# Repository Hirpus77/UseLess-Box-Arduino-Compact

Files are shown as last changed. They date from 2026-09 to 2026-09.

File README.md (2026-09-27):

# Useless Box Arduino Compact (v1.5)

Useless box compatta con Arduino Nano e un solo servo: levetta su **D9**, servo su **D10**, 29 comportamenti più Party Mode.

Per iniziare leggi [`INIZIA_QUI.md`](INIZIA_QUI.md) e la guida PDF in [`01_GUIDA/`](01_GUIDA/).

## Contenuto

| Cartella | Contenuto |
|---|---|
| `01_GUIDA/` | Guida PDF v1.5, istruzioni di cablaggio e posizionamento, verifiche STL |
| `02_ARDUINO/` | Sketch: prova levetta, calibrazione braccio, programma a 29 comportamenti, programma base opzionale |
| `03_STL_STAMPA/` | I nove pezzi da stampare in 3D |
| `04_STEP_MODIFICABILI/` | Gli stessi pezzi in formato STEP, modificabili |
| `05_IMMAGINI/` | Schemi di cablaggio, quote e montaggio |

`SHA256SUMS.txt` permette di verificare l'integrità dei file: `sha256sum -c SHA256SUMS.txt`.

## Ordine di lavoro

1. Stampa i nove file di `03_STL_STAMPA`.
2. Carica `prova_levetta.ino` per verificare la levetta su D9.
3. Carica `calibra_braccio.ino` e annota i quattro angoli.
4. Inserisci gli angoli in `useless_box_29_comportamenti.ino` e caricalo.

Con il computer collegato via USB il ponticello RUN va tolto; il servo si muove solo con l'alimentazione esterna a 5 V accesa.

## Licenza

Il progetto usa licenze diverse per tipo di contenuto:

| Contenuto | Licenza | File |
|---|---|---|
| Codice (`02_ARDUINO/`) | MIT | [`LICENSE`](LICENSE) |
| Hardware (`03_STL_STAMPA/`, `04_STEP_MODIFICABILI/`) | CERN-OHL-P v2 | [`LICENSE-hardware`](LICENSE-hardware) |
| Documentazione e immagini (`01_GUIDA/`, `05_IMMAGINI/`, file di testo) | CC BY-SA 4.0 | [`LICENSE-docs`](LICENSE-docs) |

© 2026 Hirpus77

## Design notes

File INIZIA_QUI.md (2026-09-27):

# Useless box compatta v1.5 - INIZIA QUI

Questa cartella contiene una sola copia di ogni file corrente.

## Ordine consigliato

1. Leggi `01_GUIDA/Guida_useless_box_compatta_v1.5_D9_D10.pdf`.
2. Stampa soltanto i nove file presenti in `03_STL_STAMPA`.
3. Esegui prima `02_ARDUINO/prova_levetta/prova_levetta.ino`.
4. Esegui `02_ARDUINO/calibra_braccio/calibra_braccio.ino` e annota i quattro angoli.
5. Inserisci gli angoli in `02_ARDUINO/useless_box_29_comportamenti/useless_box_29_comportamenti.ino`.
6. Metti `ABILITATO = true`, prova i comportamenti 1, 8 e 26, poi rimetti `COMPORTAMENTO_TEST = 0`.

## Pin definitivi

- D10 / verde: segnale servo.
- D9 / giallo: levetta.
- blu GND: centrale COM della levetta.
- rosso 5V: giunto RUN e distributore +5 V.
- nero GND: distributore GND.
- D2: libero.

Con il Mac collegato RUN deve essere tolto. Il servo si muove soltanto con il 5 V esterno collegato e acceso.

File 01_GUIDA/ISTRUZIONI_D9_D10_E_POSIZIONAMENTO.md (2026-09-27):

# Cablaggio definitivo con distributori da 5 poli e giunto da 2 poli

Questa revisione usa i componenti già acquistati:

- due distributori a leva da 5 poli;
- due giunti a leva da 2 poli;
- i cinque fili già saldati alla basetta A;
- la slitta C10 e la basetta 50 × 34 mm già previste dal progetto.

D2 resta libero. Non servono una seconda piastra, nuovi fori o modifiche alla scatola.

## 1. Mappa dei cinque fili

| Colore | Pin Nano | Destinazione |
|---|---|---|
| Verde | D10 | Giunto da 2 poli, poi segnale `S` del servo |
| Giallo | D9 | Piedino laterale `ON` della levetta |
| Blu | GND | Piedino centrale `COM` della levetta |
| Rosso | 5V | RUN, poi distributore `+5 V` da 5 poli |
| Nero | GND | Distributore GND da 5 poli |

Tutti i programmi leggono la levetta da D9 con `INPUT_PULLUP`.

## 2. Levetta

- centrale `COM`: blu GND;
- laterale che chiude il contatto nella posizione ON: giallo D9;
- altro laterale: libero e isolato.

Se ON e OFF risultano invertiti, spostare soltanto il giallo sull'altro piedino laterale.

## 3. Servo

Al servo arrivano esattamente tre collegamenti:

1. verde D10 attraverso il giunto da 2 poli al segnale `S`;
2. rosso dal distributore +5 V al rosso centrale del servo;
3. nero dal distributore GND al nero o marrone del servo.

## 4. Distributore +5 V da 5 poli

Montarlo sulla faccia della basetta rivolta verso il centro della scatola. Usare quattro sedi:

1. positivo dell'alimentatore esterno;
2. positivo del servo;
3. positivo del condensatore;
4. uscita di RUN.

La quinta sede resta libera. L'altro lato di RUN va al filo rosso 5V del Nano.

## 5. Distributore GND da 5 poli

Montarlo sulla faccia opposta della stessa basetta, rivolta verso la parete destra. Usare quattro sedi:

1. negativo dell'alimentatore esterno;
2. GND nero o marrone del servo;
3. negativo del condensatore, identificato dalla fascia;
4. filo nero GND del Nano.

La quinta sede resta libera. Il blu non entra nel distributore: va direttamente al COM della levetta.

## 6. Giunti da 2 poli

- giunto D10, prima sede: verde proveniente da D10;
- giunto D10, seconda sede: filo del contatto `S` del servo;
- giunto RUN, prima sede: rosso proveniente dal 5V del Nano;
- giunto RUN, seconda sede: ingresso del distributore +5 V.

I due giunti restano su cavetti corti fissati con una fascetta al bordo superiore della C10. Nel giunto D10 non collegare 5 V o GND.

## 7. Preparazione della basetta C10

Questa operazione si esegue fuori dalla scatola.

1. Verificare che ciascun distributore non superi 30 × 19 × 10 mm.
2. Posizionare i due distributori schiena contro schiena, nella zona centrale della basetta.
3. Mettere il +5 V sulla faccia che guarderà il centro della scatola.
4. Mettere il GND sulla faccia che guarderà la parete destra.
5. Fissarli insieme alla basetta con una fascetta sottile. Non affidarsi soltanto al biadesivo.
6. Fissare il condensatore orizzontale nella fascia superiore della faccia centrale.
7. Lasciare RUN e giunto D10 su cavetti corti, legati al bordo superiore e raggiungibili dopo aver tolto il coperchio.
8. Cablare completamente il distributore GND sul lato parete: dopo il montaggio non sarà comodo aprire le leve.
9. Inserire la basetta nelle guide C10 con i componenti orientati come indicato nello schema.
10. Usare le fascette previste dalla C10 senza stringere fino a deformare la basetta.
11. Fissare la C10 nei due fori esistenti con le due M3 × 8 previste.

Le quote esatte sono nelle tavole `04_piastra_C10_quote_mm.png` e
`05_ingombri_C10_scatola_quote_mm.png`.

## 8. Posizioni nella scatola

- C09: basetta A e Nano;
- C10: basetta 50 × 34 mm con i due distributori sulle facce opposte;
- C05: servo;
- C06: ingresso del cavo 5 V bloccato con due fascette;
- coperchio: levetta.

Non stampare alcuna C11: è stata eliminata dopo la verifica di collisione.

## 9. Percorso dei cavi

1. Dalla C06 portare rosso e nero lungo la parete destra fino alla C10.
2. Portare verde, rosso e nero dalla C10 verso il servo restando aderenti al fondo.
3. Portare rosso e nero del Nano dalla C09 ai due distributori.
4. Portare giallo D9 e blu GND direttamente alla levetta.
5. Lasciare un arco di servizio per sollevare il coperchio.
6. Nessun filo deve attraversare la zona di movimento del braccio.

## 10. Controlli senza alimentazione

1. +5 V e GND non devono essere in continuità.
2. Nero Nano, negativo alimentatore e GND servo devono essere in continuità.
3. Verde D10 e segnale `S` del servo devono essere in continuità attraverso il giunto da 2 poli.
4. Blu GND e COM della levetta devono essere in continuità.
5. Levetta ON: giallo D9 e blu GND devono essere in continuità.
6. Levetta OFF: giallo D9 e blu GND devono essere separati.
7. D2 deve risultare scollegato.
8. RUN tolto: il 5V del Nano deve essere separato dal +5 V esterno.
9. RUN inserito: il 5V del Nano deve essere collegato al +5 V esterno.

## 11. Prova con il Mac

1. Spegnere il 5 V esterno.
2. Togliere RUN.
3. Collegare il Nano al Mac.
4. Caricare `prova_levetta.ino` e aprire il monitor seriale a 115200 baud.
5. Verificare ON e OFF.
6. Caricare `calibra_braccio.ino`.
7. Collegare il servo a impianto spento.
8. Accendere il 5 V esterno per muovere il servo.

Durante la calibrazione: Mac collegato, RUN tolto, alimentatore esterno acceso.

## 12. Uso autonomo

1. Spegnere il 5 V esterno.
2. Scollegare la USB-C dal Mac.
3. Inserire RUN.
4. Accendere il 5 V esterno.

## 13. Pin usati dal codice

```cpp
const byte PIN_ARM = 10;
const byte PIN_LEVETTA = 9;
```

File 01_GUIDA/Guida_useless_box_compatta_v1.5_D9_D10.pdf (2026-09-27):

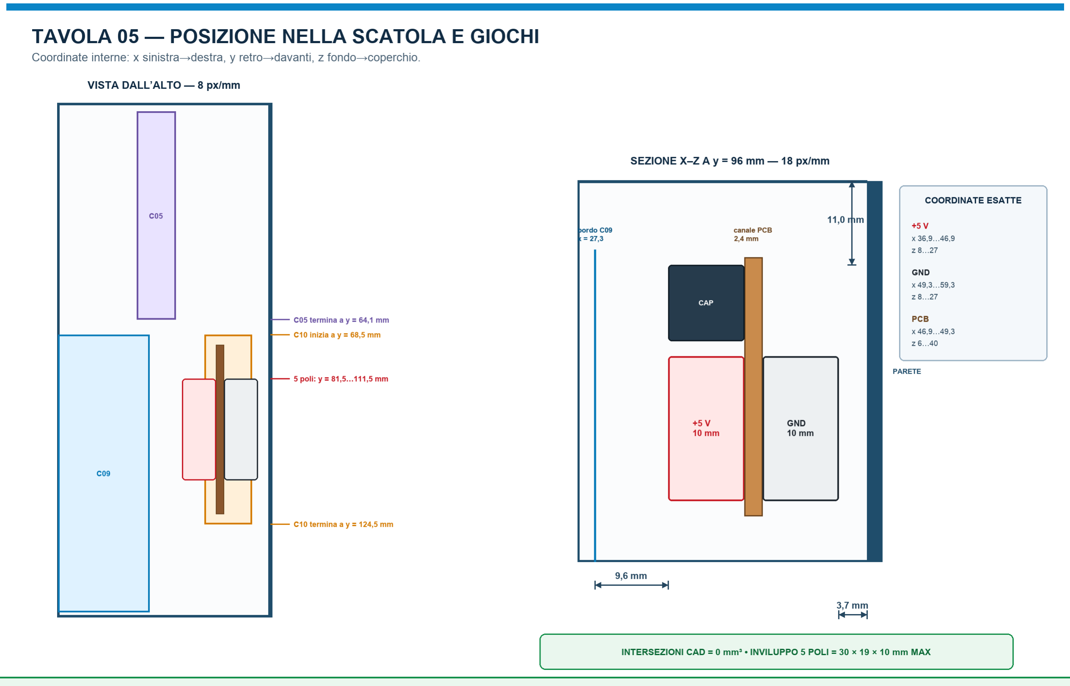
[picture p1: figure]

Useless box compatta v1.5 - D9 levetta / D10 servo | pag. 1

# Useless box compatta - versione completa 1.5

Cablaggio definitivo D9/D10, parti meccaniche corrette e calibrazione dei 29 comportamenti

Configurazione definitiva: un servo MG996R/MG995 comandato da D10; levetta letta da D9; D2 libero; alimentatore esterno 5 V / 3 A; due distributori da 5 poli e due giunti da 2 poli.

Elemento | Versione inclusa
C01 e C02 | corpo largo 68 mm; foro USB-C 15,30 x 5,30 mm; riferimenti coperchio corretti
C04 | braccio con sede squadretta D8,9
C05 | staffa servo rinforzata
C06 | fermacavo 5 V con due fascette
C10 | slitta basetta B rinforzata V2, basetta 50 x 34 mm
Arduino | D9 levetta, D10 servo, quattro sketch completi

## 1. File da stampare

File | Quantita | Indicazione di stampa
C01 corpo | 1 | fondo sul piatto; PLA; 0,20 mm; 4 pareti; 20%; senza supporti
C02 coperchio | 1 | faccia esterna sul piatto; 4 pareti; 20%; senza supporti
C03 sportello | 1 | faccia superiore sul piatto
C04 braccio D8,9 | 1 | lato della squadretta sul piatto; 5 pareti; 50%
C05 staffa servo | 1 | sul fianco come nello STL; 5 pareti; 40-50%
C06 fermacavo | 1 | piatta; due fascette
C08 piedino | 4 | piatto; incollare alla fine
C09 slitta A | 1 | base piatta; 4 pareti; 25%
C10 slitta B | 1 | base piatta; 5 pareti; 35-45%

Non stampare C11. La seconda piastra e stata eliminata: collideva con C10. I due distributori da 5 poli stanno sulle facce opposte della stessa basetta montata in C10.

Quote principali: C01 e C02 misurano 68 x 157 mm. Il vano interno e 63 x 152 x 50 mm. Il foro USB-C utile e 15,30 x 5,30 mm con tolleranza minima.

## 2. Viti e minuteria

Uso | Quantita e misura
MG996R/MG995 nella C05 | 4 x M3x12, 4 rondelle M3, 4 dadi M3; usare M3x16 se restano i gommini
C05, C09 e C10 sul fondo | 6 x M3x6 complessive, inserite dal basso
Coperchio | 2 x M3x10
Perno sportello | 1 x M3x25
C04 sulla squadretta | 2 viti piccole del servo
Squadretta sull albero | 1 vite centrale del servo
C09 e C10 | 4 fascette larghe massimo 2,5 mm
C06 | 2 fascette per bloccare il cavo 5 V

Totale viti metriche: 13. A queste si aggiungono le 3 viti fornite con il servo per squadretta e braccio.

Non avvitare le quattro M3 del servo direttamente nel PLA. Le viti attraversano asola C05 e aletta del servo; rondella e dado chiudono sul lato opposto.

## 3. Montaggio del servo e del braccio

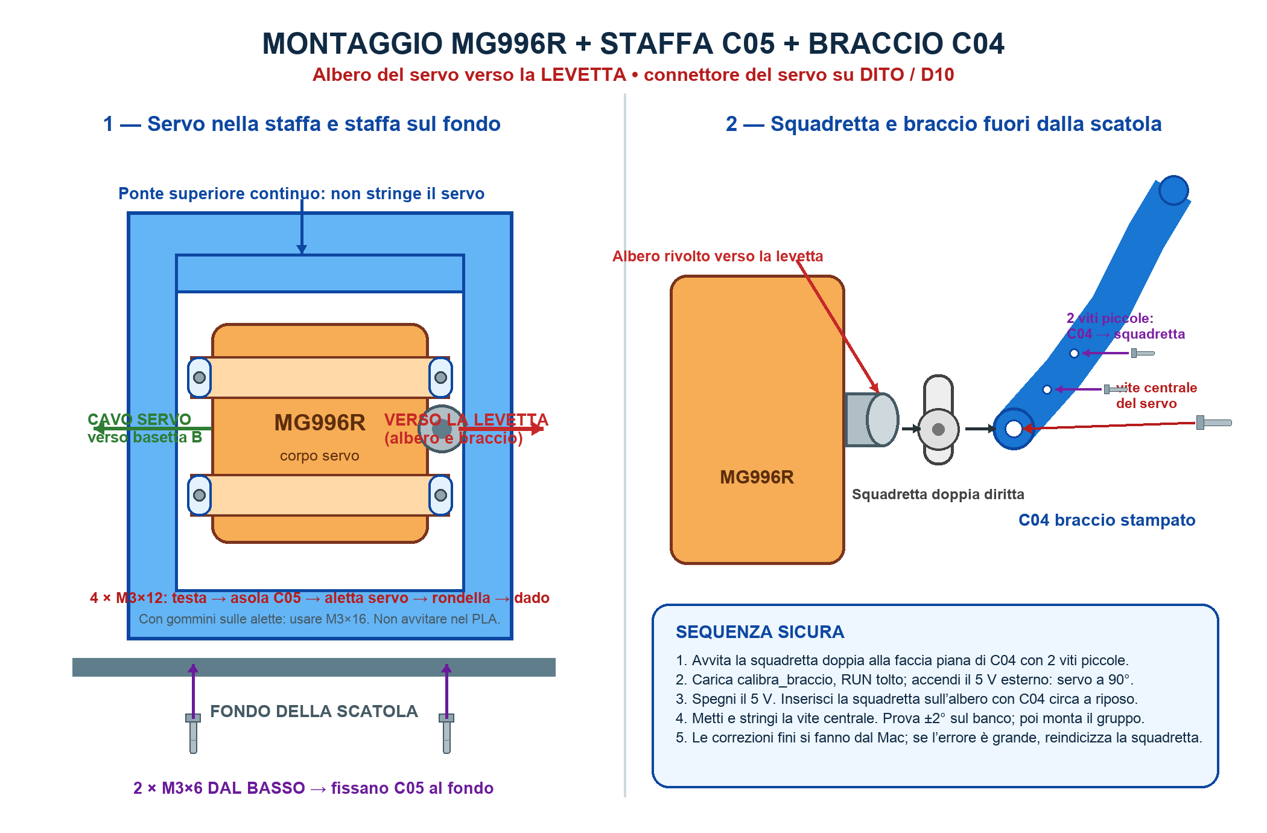
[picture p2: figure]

Orientamento: albero e braccio dal lato della levetta. Il cavo del servo esce dal lato opposto, verso l elettronica.

Sequenza: fissa C05 al fondo con due M3x6; inserisci il servo lateralmente; monta quattro M3 con rondelle e dadi; centra il servo nelle asole; serra a croce.

La squadretta doppia entra nella sede D8,9 di C04. Fissala con due viti piccole. Centra elettricamente il servo a 90 gradi, spegni il 5 V esterno, inserisci la squadretta sull albero e stringi la vite centrale.

## 4. I cinque fili della basetta A

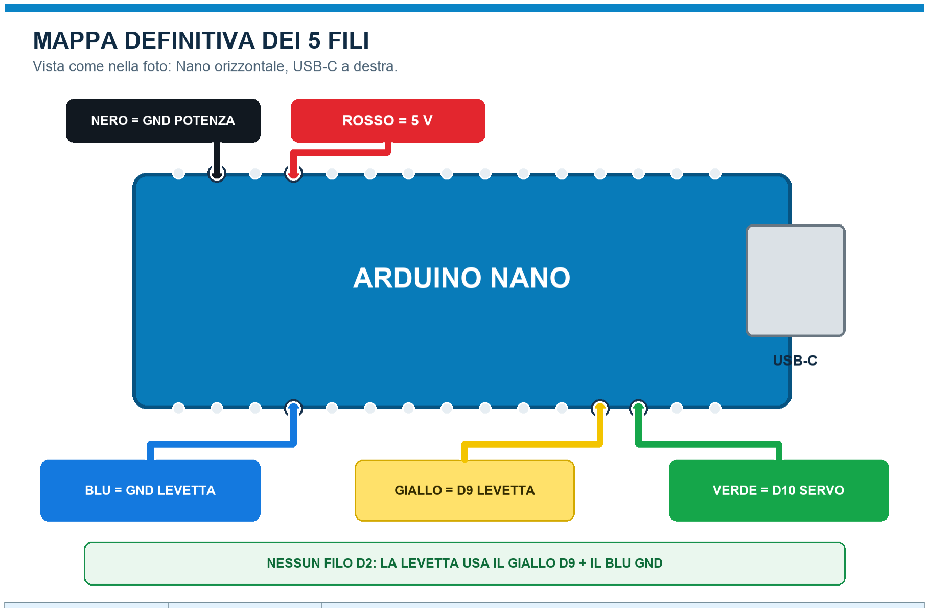
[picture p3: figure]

Colore | Pin Nano | Destinazione
Verde | D10 | giunto da 2 poli, poi segnale S del servo
Giallo | D9 | terminale laterale ON della levetta
Blu | GND | terminale centrale COM della levetta
Rosso | 5V | giunto RUN, poi distributore +5 V
Nero | GND | distributore GND

D2 resta scollegato. Non aggiungere un sesto filo.

## 5. Schema elettrico definitivo

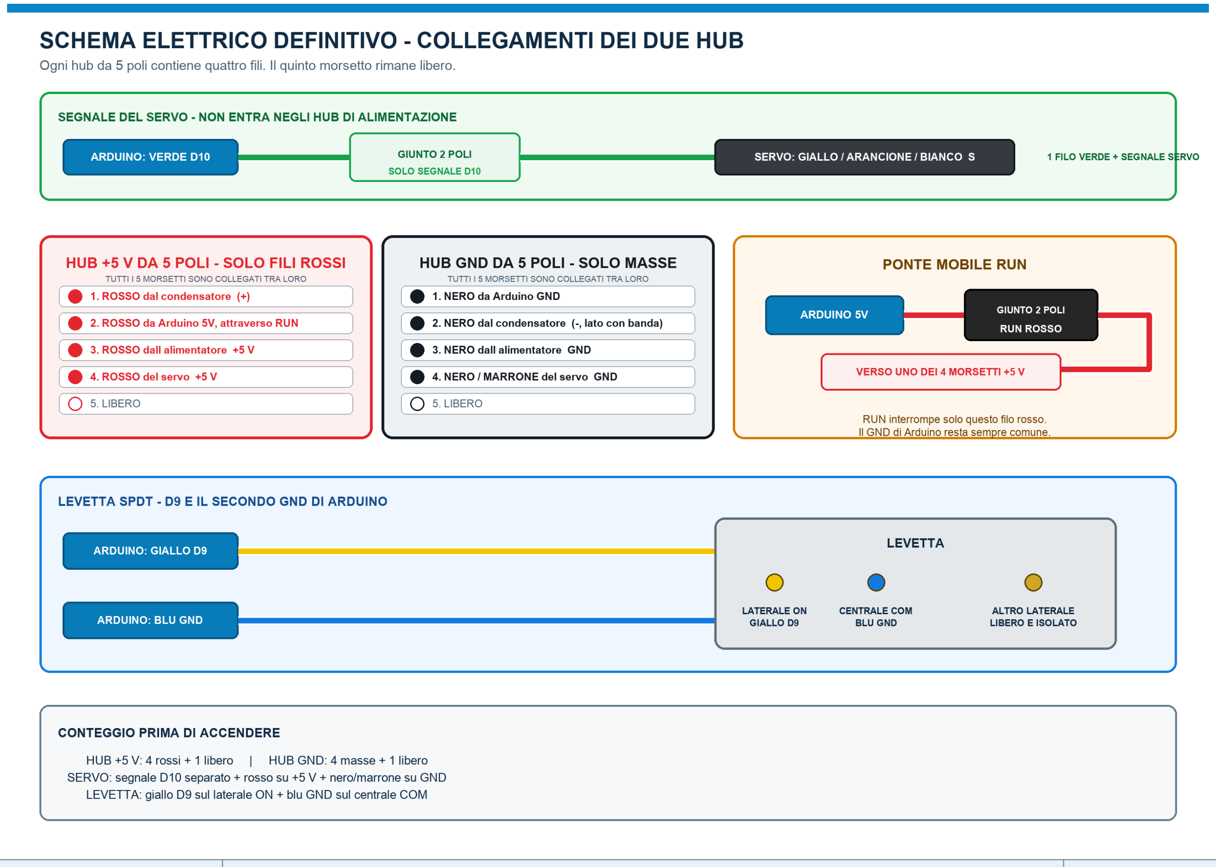
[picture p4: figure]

Hub | Quattro morsetti occupati | Quinto morsetto
+5 V, solo rossi | condensatore +; Arduino 5V attraverso RUN; alimentatore +5V; servo +5V | libero
GND, solo masse | Arduino GND nero; condensatore -; alimentatore GND; servo nero/marrone | libero
Fuori dagli hub: verde D10 passa nel giunto a 2 poli e va al segnale S del servo. Giallo D9 va al laterale ON della levetta; blu GND va al centrale COM.

RUN: interrompe soltanto il filo rosso tra 5V Arduino e hub +5 V. Il GND nero di Arduino rimane sempre collegato all hub GND.

## 6. Posizione dei componenti

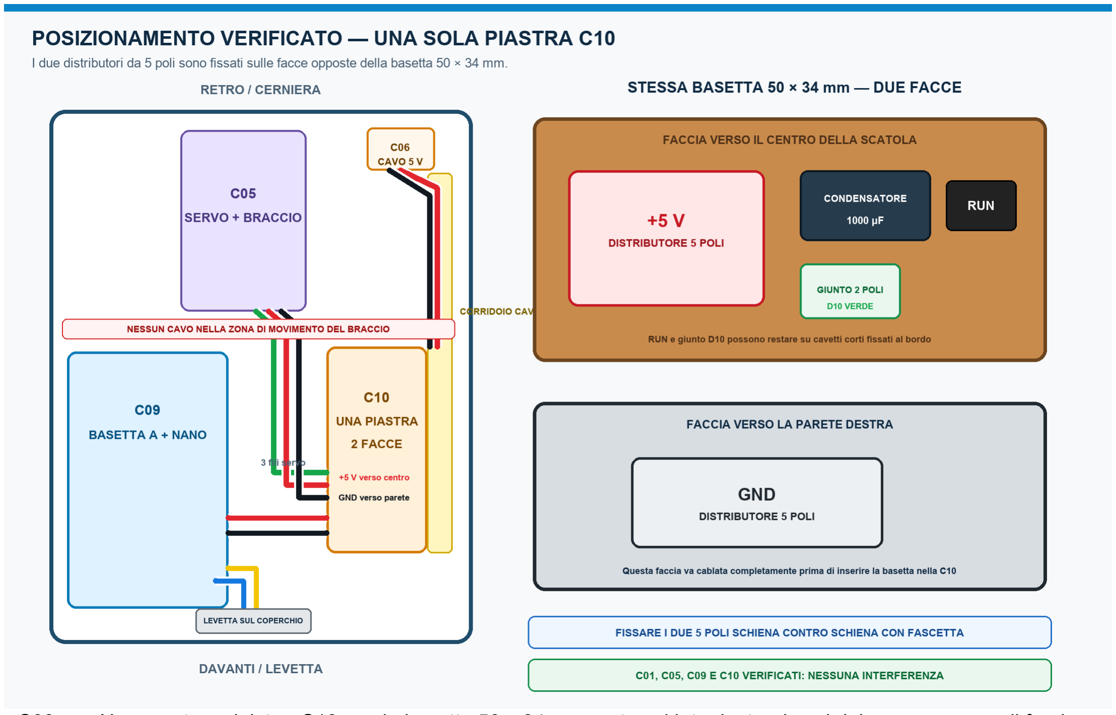
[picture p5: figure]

C09 con Nano resta a sinistra. C10 con la basetta 50 x 34 mm resta sul lato destro. I cavi del servo seguono il fondo e non entrano nella zona di movimento del braccio.

Il distributore +5 V guarda il centro della scatola. Il distributore GND guarda la parete destra e deve essere cablato completamente prima di inserire la basetta nelle guide C10.

## 7. Basetta C10: quote di montaggio

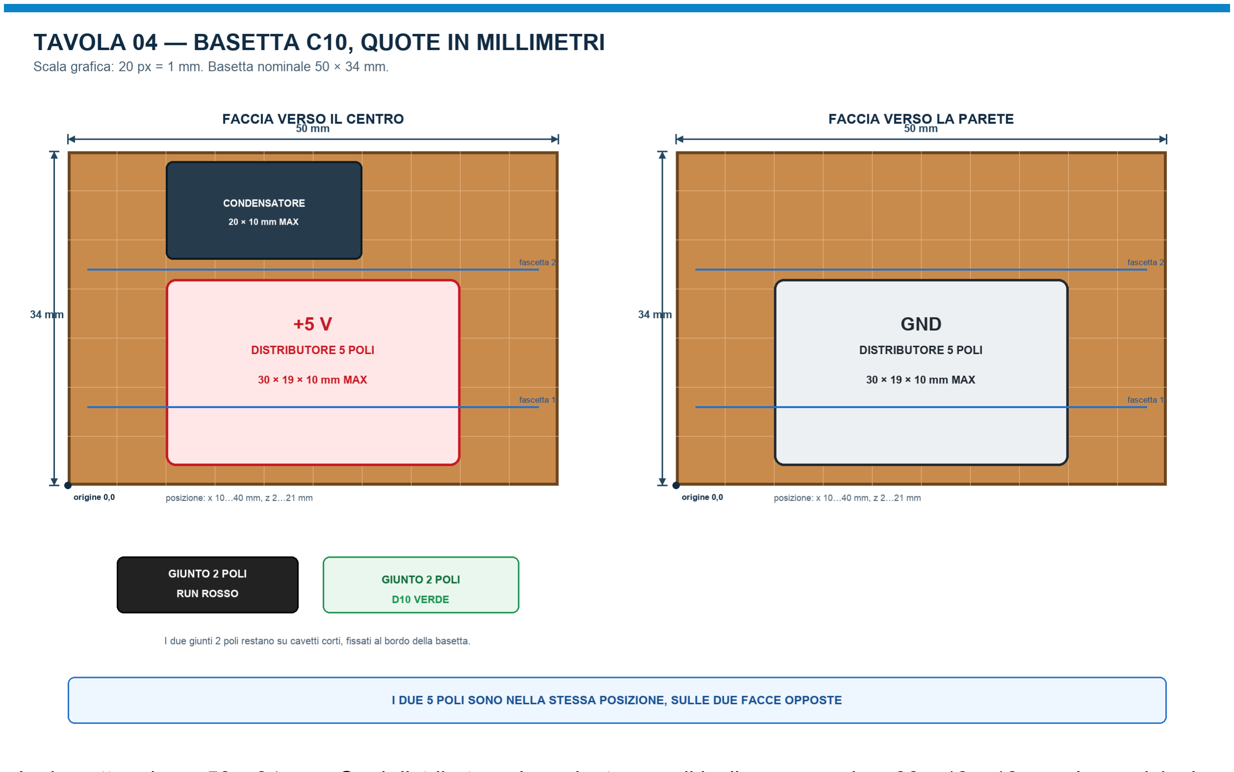
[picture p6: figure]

La basetta misura 50 x 34 mm. Ogni distributore deve rientrare nell inviluppo massimo 30 x 19 x 10 mm. Le posizioni indicate sono x 10-40 mm e z 2-21 mm sulle due facce opposte.

Fissa i due distributori schiena contro schiena con la basetta in mezzo. Usa le due fascette indicate. I due giunti da 2 poli RUN e D10 restano su cavetti corti fissati al bordo.

## 8. Ingombri verificati nella scatola

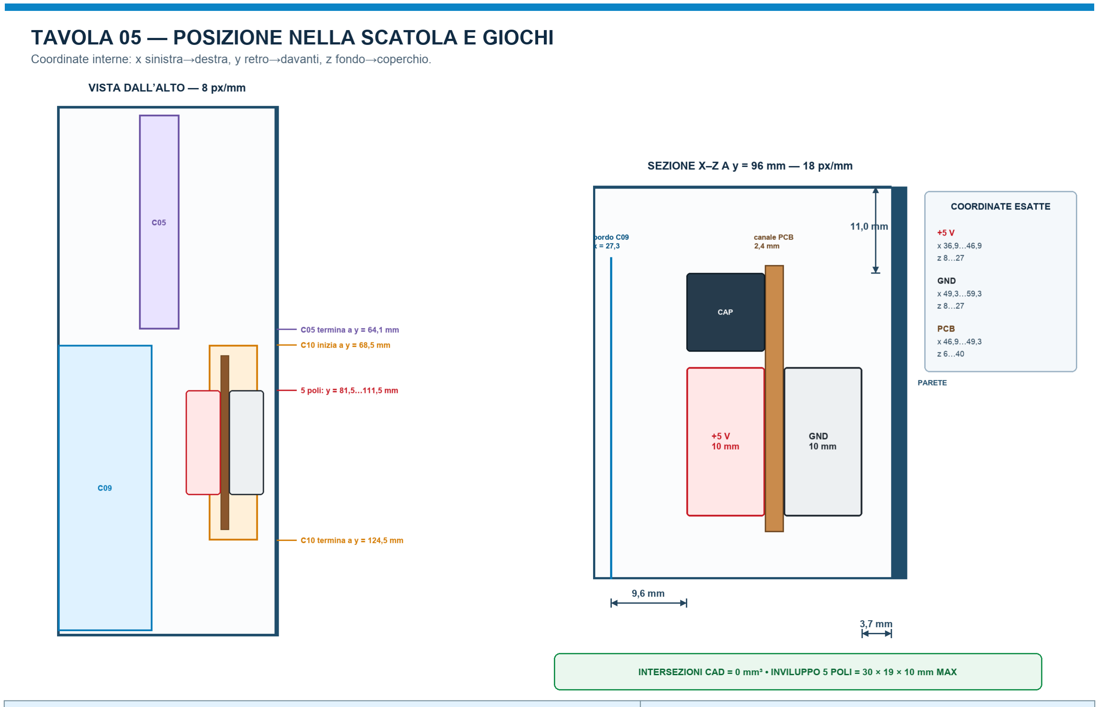
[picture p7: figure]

Controllo | Gioco verificato
Distributore GND - parete destra | 3,7 mm
Distributore +5 V - bordo C09 | 9,6 mm
Condensatore - coperchio | 11,0 mm
Intersezioni nel controllo CAD | 0 mm3

Il controllo e valido soltanto se ciascun distributore non supera 30 x 19 x 10 mm.

## 9. Ordine completo di montaggio

Passo | Operazione
1 | Stampa e prova a secco C09, C10 e C05 con le parti reali.
2 | Prepara C09 con basetta A e Nano fuori dalla scatola; applica due fascette.
3 | Prepara la basetta 50 x 34 mm con i due distributori sulle facce opposte e il condensatore.
4 | Cabla completamente il lato GND; inserisci la basetta nelle guide C10; applica due fascette.
5 | Monta il cavo 5 V nella C06 e bloccalo con due fascette antistrappo.
6 | Fissa C09, C10 e C05 dal basso con sei M3x6.
7 | Collega alimentazione, RUN, D10, servo e levetta secondo lo schema.
8 | Monta sportello, coperchio e levetta. Lascia un arco di cavo per sollevare il coperchio.
9 | Centra e monta il braccio; esegui la calibrazione dal Mac.
10 | Incolla i quattro piedini C08 solo alla fine.

Nessun cavo deve attraversare la corsa del braccio o toccare la squadretta del servo.

## 10. Controlli elettrici senza alimentazione

Misura | Risultato richiesto
+5 V verso GND | nessuna continuita
Nero Nano - negativo alimentatore - GND servo | continuita
Verde D10 - segnale S servo | continuita attraverso il giunto D10
Blu - COM levetta | continuita
Levetta ON: giallo - blu | continuita
Levetta OFF: giallo - blu | separati
RUN tolto: 5V Nano - +5 V esterno | separati
RUN inserito: 5V Nano - +5 V esterno | continuita
D2 | scollegato

Banco con Mac: spegni il 5 V esterno, togli RUN, collega la USB, poi accendi il 5 V esterno solo quando il servo deve muoversi.

Uso autonomo: spegni il 5 V, scollega la USB, inserisci RUN, poi riaccendi il 5 V.

## 11. Arduino IDE sul Mac

1. Collega il Nano con un cavo USB-C dati. RUN deve essere tolto.
2. In Arduino IDE seleziona Scheda - Arduino AVR Boards - Arduino Nano e la porta seriale comparsa.
3. Se il caricamento fallisce, prova Processore - ATmega328P (Old Bootloader).
4. Apri il Monitor seriale a 115200 baud.
5. Carica prima prova_levetta.ino. Questa prova non richiede il servo.
6. Carica poi calibra_braccio.ino. Per muovere il servo serve il 5 V esterno acceso.
Situazione | USB Mac | RUN | 5 V esterno
Caricamento sketch | collegata | tolto | spento
Prova levetta | collegata | tolto | spento
Calibrazione servo | collegata | tolto | acceso
Uso autonomo | scollegata | inserito | acceso

## 12. Prova della levetta

1. Apri 02_ARDUINO/prova_levetta/prova_levetta.ino e caricalo.
2. Apri il Monitor seriale a 115200 baud.
3. Porta la leva verso lo sportello: deve comparire ON e il LED L deve accendersi.
4. Riporta la leva indietro: deve comparire OFF e il LED L deve spegnersi.

Se ON e OFF sono invertiti, spegni tutto e sposta soltanto il filo giallo D9 sull altro terminale laterale. Il blu resta sempre sul centrale COM.

Esegui dieci commutazioni consecutive. Non devono comparire cambi casuali.

## 13. Centratura e calibrazione del braccio

1. Tieni il braccio scollegato dall albero. Carica calibra_braccio.ino con RUN tolto.
2. Accendi il 5 V esterno. Il servo va a 90 gradi. Questo indica la posizione elettrica centrale; non impone che il dito sia orizzontale o verticale.
3. Spegni il 5 V, monta squadretta e braccio circa nella posizione di riposo e stringi fuori dalla scatola.
4. Monta il gruppo. Riaccendi il 5 V e usa i comandi del Monitor seriale.
Comando | Effetto
+ / - | spostamento di 2 gradi
> / < | spostamento di 1 grado
r | ritorno lento a 90 gradi
s | stacca il segnale e libera il servo
p | stampa angolo e stato levetta
l | legge lo stato della levetta

## 14. Trovare i quattro angoli

Nome | Come identificarlo
ARM_RIPOSO | braccio dentro, sportello appoggiato, nessuna pressione e nessun ronzio
ARM_SBIRCIATA | punta appena visibile e sportello sollevato poco
ARM_QUASI | ultimo angolo vicino alla levetta senza muoverla; arretra 1-2 gradi come margine
ARM_SPINTA | primo angolo che porta la levetta da ON a OFF, poi soltanto 2 gradi aggiuntivi
Premi + tre volte. Se la punta sale verso la levetta usa angoli crescenti; se scende usa la direzione opposta. I quattro valori devono risultare tutti crescenti oppure tutti decrescenti.

La corsa RIPOSO-SPINTA ammessa dal programma e compresa tra 45 e 110 gradi. Durante la ricerca resta tra 10 e 170 gradi.

## 15. Programma con 29 comportamenti

1. Apri 02_ARDUINO/useless_box_29_comportamenti/useless_box_29_comportamenti.ino.
2. Sostituisci i valori di esempio ARM_RIPOSO, ARM_SBIRCIATA, ARM_QUASI e ARM_SPINTA con quelli misurati.
3. Lascia PIN_ARM = 10 e PIN_LEVETTA = 9.
4. Imposta ABILITATO = true.
5. Per il primo collaudo usa COMPORTAMENTO_TEST = 1, poi 8 e 26. Dopo le prove rimettilo a 0.
6. Carica il programma definitivo. Con TEST = 0 tornano la scelta automatica dei 29 comportamenti e il Party Mode.

Se compare Levetta ancora ON, aumenta ARM_SPINTA di 2 gradi nella direzione utile. Se il servo urta, ronza o forza, riduci la corsa e ricontrolla QUASI e SPINTA.

## 16. Collaudo finale e diagnosi

Sintomo | Controllo
Monitor funziona ma servo fermo | 5 V esterno acceso; verde su D10/S; massa comune; almeno 4,8 V durante il comando
Servo si muove senza controllo | GND servo e GND Nano realmente comuni; segnale D10 integro; nessun falso contatto nel giunto
Nano si spegne o si riavvia | tensione sotto carico; polarita; alimentatore; condensatore vicino ai distributori
Levetta non cambia stato | giallo D9 sul laterale attivo; blu sul centrale COM; INPUT_PULLUP
Servo ronza a riposo | ridurre pressione meccanica; correggere ARM_RIPOSO; verificare che il braccio non tocchi
Braccio urta la scatola | orientamento dell albero; sede D8,9; reindicizzare la squadretta a corrente spenta
Prova finale: esegui 20 cicli. La tensione deve restare almeno 4,8 V; la Nano non deve riavviarsi; il servo non deve restare bloccato o caldo.

Verifiche file: nove STL inclusi, tutti appartenenti alla revisione corrente. C01/C02 sono la versione larga 68 mm; C04 e la revisione D8,9; C06 e C10 sono le revisioni rinforzate. Il controllo di ingombro C01/C05/C09/C10 con i due distributori ha dato 0 mm3 di intersezioni.

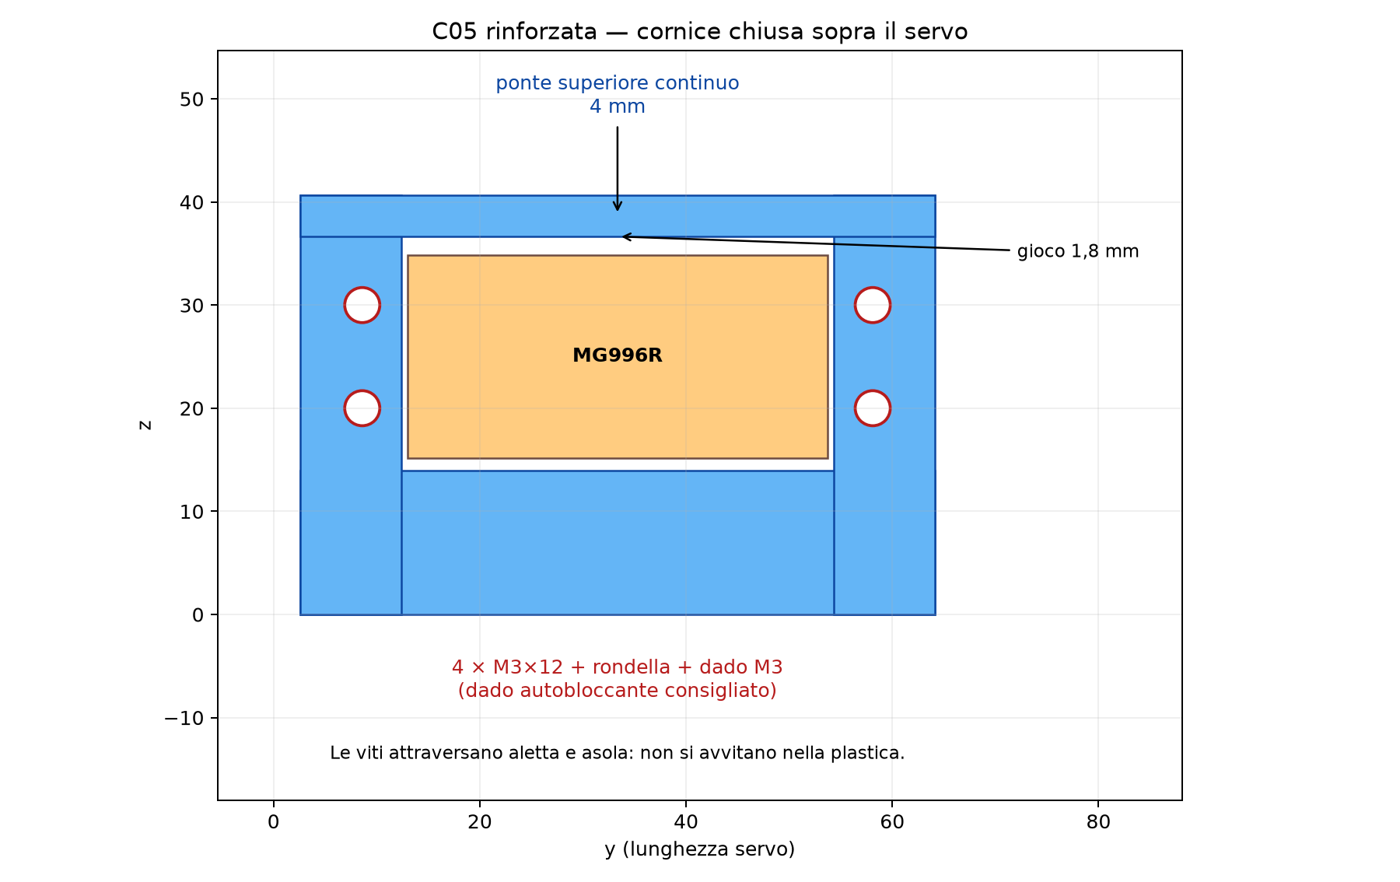
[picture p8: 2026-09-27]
05_IMMAGINI/07_staffa_C05.png

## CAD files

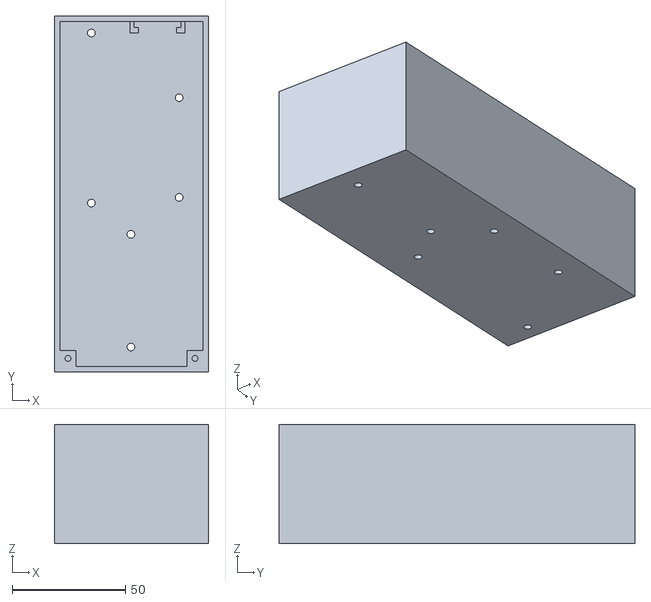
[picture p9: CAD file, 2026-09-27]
03_STL_STAMPA/C01_corpo_5mm_USB_Nano_15.30x5.30.stl
68.0 x 157.0 x 52.5

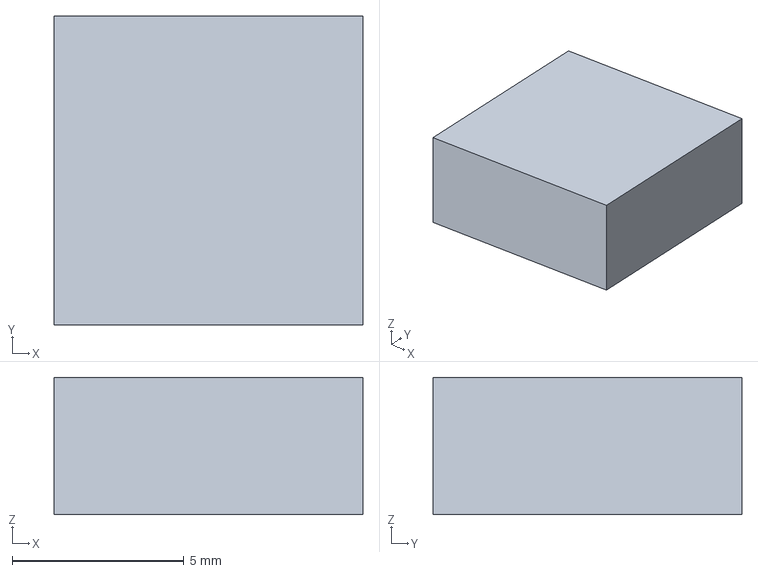
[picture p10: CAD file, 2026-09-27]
04_STEP_MODIFICABILI/C08_piedino_9x9x4.step
9.00 x 9.00 x 4.00 mm

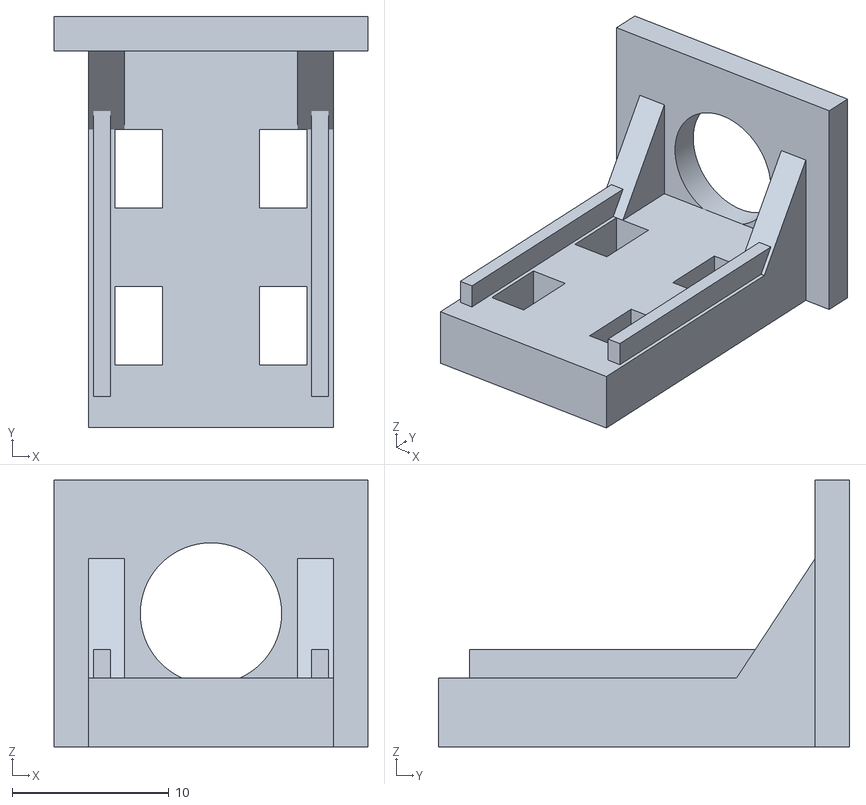
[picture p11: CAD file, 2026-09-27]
03_STL_STAMPA/C06_piastra_cavo_5V_fermacavo_2_fascette.stl
20.0 x 26.2 x 17.0

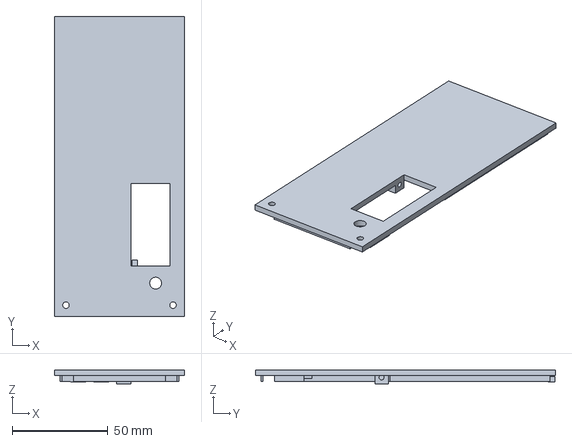
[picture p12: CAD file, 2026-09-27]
04_STEP_MODIFICABILI/C02_coperchio_5mm_interruttore_allineato.step
68.0 x 157.0 x 7.50 mm

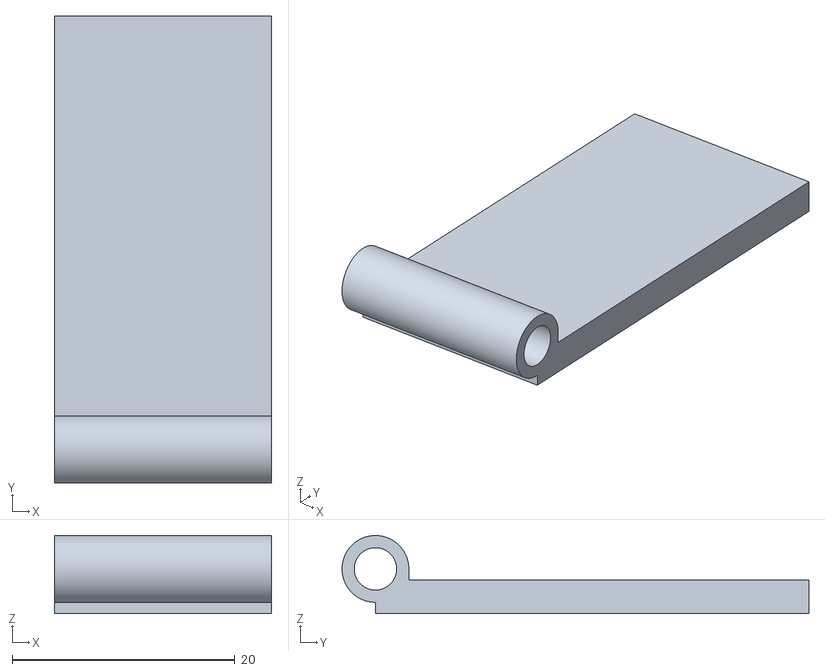
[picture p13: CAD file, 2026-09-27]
03_STL_STAMPA/C03_sportello.stl
19.5 x 41.9 x 7.00

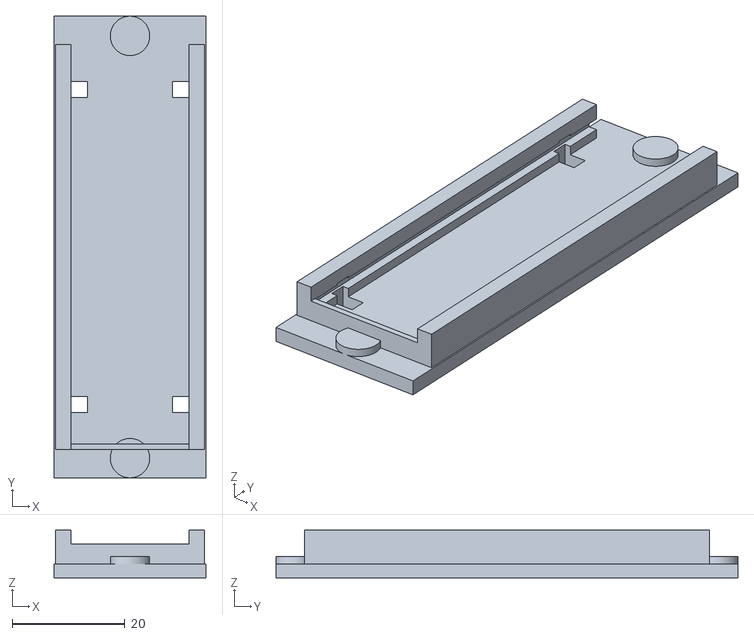
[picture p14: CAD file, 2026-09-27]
03_STL_STAMPA/C09_slitta_basetta_A_23.5x70.stl
27.0 x 82.0 x 8.50

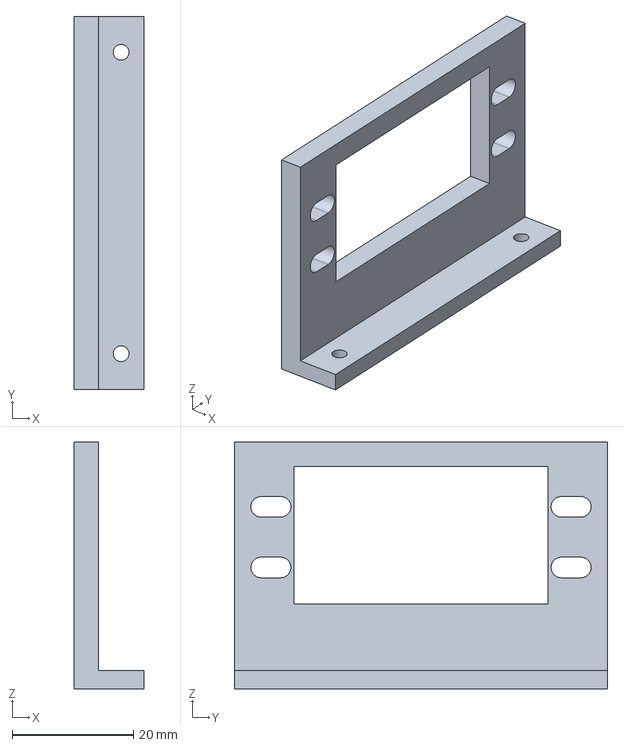
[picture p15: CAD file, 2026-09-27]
04_STEP_MODIFICABILI/C05_staffa_servo_RINFORZATA.step
11.5 x 61.5 x 40.6 mm

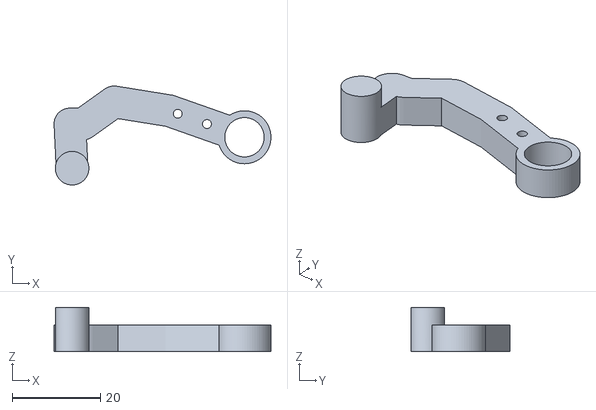
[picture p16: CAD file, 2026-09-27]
03_STL_STAMPA/C04_braccio_incastro_squadretta_D8.9.stl
49.1 x 22.4 x 10.0

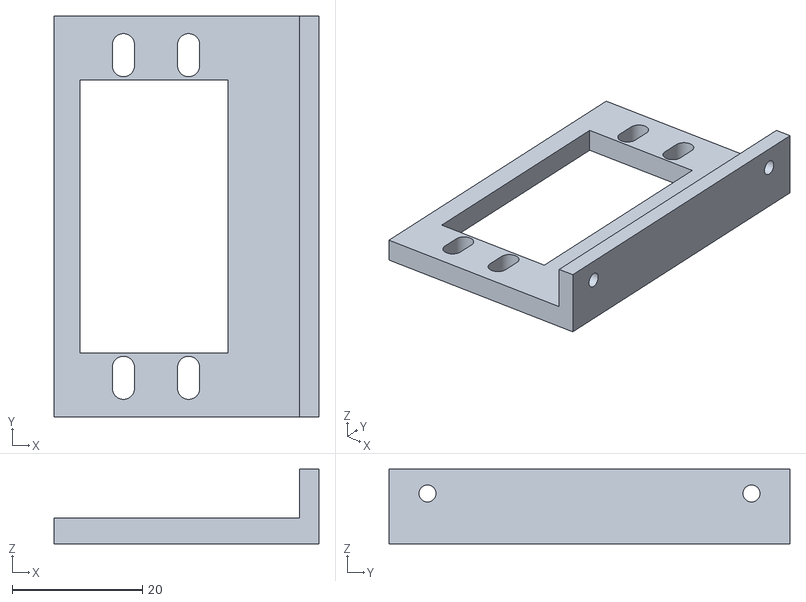
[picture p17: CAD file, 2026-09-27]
03_STL_STAMPA/C05_staffa_servo_RINFORZATA.stl
40.7 x 61.5 x 11.5

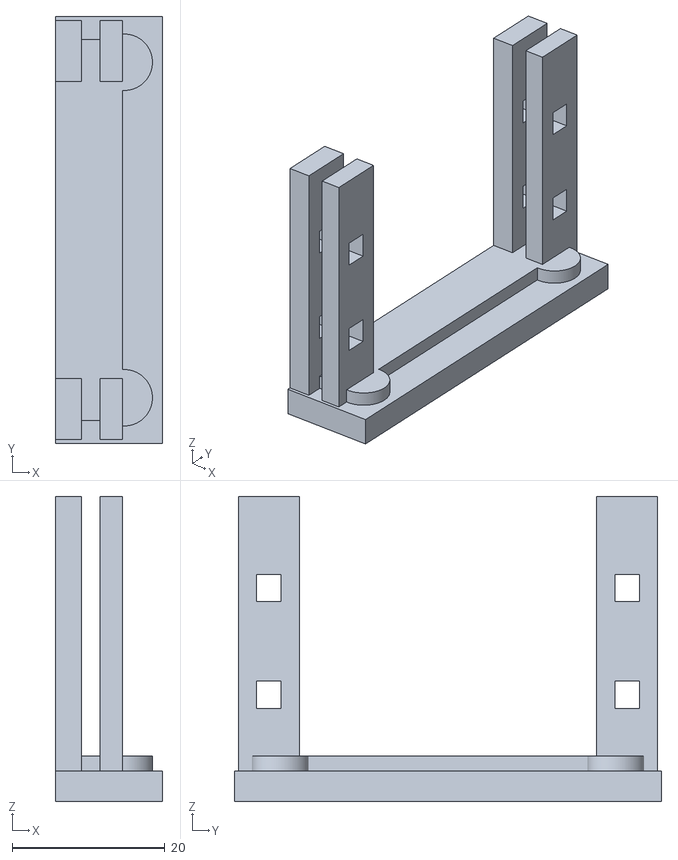
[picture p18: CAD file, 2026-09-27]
03_STL_STAMPA/C10_slitta_verticale_basetta_B_RINFORZATA_V2_50x34.stl
14.0 x 56.0 x 40.0

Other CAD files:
04_STEP_MODIFICABILI/C06_piastra_cavo_5V_fermacavo_2_fascette.step
03_STL_STAMPA/C08_piedino_9x9x4.stl
04_STEP_MODIFICABILI/C09_slitta_basetta_A_23.5x70.step
04_STEP_MODIFICABILI/C03_sportello.step
04_STEP_MODIFICABILI/C01_corpo_5mm_USB_Nano_15.30x5.30.step
04_STEP_MODIFICABILI/C10_slitta_verticale_basetta_B_RINFORZATA_V2_50x34.step
03_STL_STAMPA/C02_coperchio_5mm_interruttore_allineato.stl
04_STEP_MODIFICABILI/C04_braccio_incastro_squadretta_D8.9.step

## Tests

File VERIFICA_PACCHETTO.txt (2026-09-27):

VERIFICA PACCHETTO v1.5

PDF: 17 pagine renderizzate e controllate visivamente
STL: 9 su 9 chiusi, bordi non manifold = 0
STEP: 9 file presenti
Arduino INO: 4 file; controllo sintattico superato su tutti
Pin levetta: D9 in tutti gli sketch
Pin servo: D10 in tutti gli sketch che comandano il servo
D2: non usato
Collisioni C01/C05/C09/C10 e distributori: 0 mm3
C11: esclusa dal pacchetto
Pagina 6: schema ricontrollato; hub +5 V con 4 rossi + 1 libero; hub GND con 4 masse + 1 libero

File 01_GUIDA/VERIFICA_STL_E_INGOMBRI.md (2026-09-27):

# Verifica STL e ingombri del montaggio elettrico

## File verificati nell'assieme

- C01 corpo finale v1.7, interno 63 × 152 × 50 mm;
- C05 staffa servo;
- C09 slitta basetta A;
- C10 slitta verticale rinforzata V2;
- basetta 50 × 34 mm inserita nella C10;
- due distributori da 5 poli modellati con ingombro conservativo massimo 30 × 19 × 10 mm;
- condensatore modellato con ingombro 20 × 10 × 10 mm.

## Posizione verificata

I due distributori vengono fissati schiena contro schiena sulle due facce della stessa basetta 50 × 34 mm:

- distributore +5 V sulla faccia rivolta verso il centro della scatola;
- distributore GND sulla faccia rivolta verso la parete destra;
- ingombro lungo y: 81,5–111,5 mm;
- ingombro in altezza: z 8–27 mm;
- condensatore sulla fascia superiore della faccia centrale: z 29–39 mm.

La faccia rivolta verso la parete deve essere cablata prima di inserire la basetta nella C10.

## Risultati delle intersezioni CAD

Volume di intersezione con C01, C05, C09 e C10:

- distributore +5 V: 0 mm³;
- distributore GND: 0 mm³;
- condensatore: 0 mm³.

## Margini minimi calcolati

- distributore GND–parete destra: 3,7 mm;
- distributore +5 V–C09: 9,6 mm;
- zona distributori–C05: 17,4 mm;
- distributori–appoggio inferiore C10: 2,0 mm;
- distributori–condensatore: 2,0 mm;
- condensatore–coperchio: 11,0 mm.

## Decisione

La seconda piastra C11 è stata eliminata perché interferiva con la base e con il montante anteriore della C10. Non va stampata.

La soluzione verificata usa C01, C09 e C10 già esistenti e non richiede alcuna modifica alla scatola né nuovi STL.

La verifica vale per distributori non più grandi di 30 × 19 × 10 mm. Se i pezzi acquistati superano anche una sola di queste misure, occorre ridisegnare il supporto.

## Integrità dei file STL attivi

Controllo mesh eseguito sui file correnti:

| Pezzo | Chiuso | Normali coerenti | Corpi |
|---|---:|---:|---:|
| C01 corpo finale v1.7 | sì | sì | 1 |
| C02 coperchio finale v1.7 | sì | sì | 1 |
| C03 sportello | sì | sì | 1 |
| C04 braccio D8,9 | sì | sì | 1 |
| C05 staffa servo | sì | sì | 1 |
| C06 fermacavo | sì | sì | 1 |
| C08 piedino | sì | sì | 1 |
| C09 slitta A | sì | sì | 1 |
| C10 slitta B rinforzata V2 | sì | sì | 1 |

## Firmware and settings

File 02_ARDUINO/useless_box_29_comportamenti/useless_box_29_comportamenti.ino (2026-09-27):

/*
 * USELESS BOX COMPATTA - 29 comportamenti + Party Mode + personalita'
 * Porting dello sketch UselessBox.ino (17 gennaio 2026, Nano + SG90)
 * sulla box compatta: 1 servo MG996R, braccio curvo che apre lo sportello.
 *
 * COLLEGAMENTI (come useless_box_compatta.ino)
 *   filo verde D10 = segnale del solo servo MG996R
 *   filo giallo D9 = ingresso levetta
 *   D9 = levetta (COM a GND, ON a D9)     LED "L" su D13
 *   Banco col Mac: RUN tolto; Nano dal Mac; servo dal 5 V esterno.
 *   Autonomo: Mac scollegato; RUN inserito; 5 V esterno acceso.
 *
 * DIFFERENZE RISPETTO ALLO SKETCH DI GENNAIO
 *   - Levetta con INPUT_PULLUP: ON = LOW (a gennaio: pull-down, ON = HIGH).
 *   - Le posizioni non sono piu' 10..170 gradi ma PERCENTUALI della corsa
 *     fra ARM_RIPOSO (0 %) e ARM_SPINTA (100 %), misurati con calibra_braccio.
 *   - Tutte le finte si fermano al massimo ad ARM_QUASI (punta vicina alla
 *     levetta ma senza muoverla). Solo spingi() va oltre.
 *   - spingi() si ferma appena la levetta passa a OFF; se arriva a SPINTA e la
 *     levetta e' ancora ON aspetta al massimo 0,22 s e torna (niente stallo).
 *   - Se l'utente rimette OFF durante una finta o una pausa, il braccio rientra.
 *   - I comportamenti che a gennaio "spegnevano due volte" ora la seconda volta
 *     arrivano solo ad ARM_QUASI: la levetta e' gia' OFF, spingerla ancora
 *     manderebbe il servo in stallo contro il fine corsa.
 *   - Tempi scalati: ogni velocita' 1..8 dura quanto a gennaio sull'intera corsa
 *     (min 4 ms/grado per non lanciare lo sportello).
 *   - Codice segreto per il Party Mode: 3 "sfarfallate" (ON e subito OFF entro
 *     0,35 s) in meno di 3 s. A gennaio servivano 5 ON in 3 s, impossibili
 *     mentre il braccio lavora.
 *
 * CALIBRAZIONE: usa calibra_braccio.ino e annota QUATTRO angoli:
 *   RIPOSO    braccio dentro, sportello appoggiato, nessun ronzio
 *   SBIRCIATA punta appena fuori dallo sportello
 *   QUASI     ultimo angolo in cui la levetta NON si muove ancora
 *   SPINTA    levetta scattata su OFF + 2 gradi (non di piu')
 * Poi ABILITATO = true.
 */
#include <Servo.h>

const bool ABILITATO = true;
// 0 = scelta automatica; 1..29 = forza quel comportamento per il collaudo.
// Dopo le prove rimettere sempre 0.
const byte COMPORTAMENTO_TEST = 0;
const int ARM_RIPOSO    = 80;   // valori di ESEMPIO: sostituiscili con i tuoi
const int ARM_SBIRCIATA = 104;
const int ARM_QUASI     = 152;
const int ARM_SPINTA    = 158;

const byte PIN_ARM = 10;
const byte PIN_LEVETTA = 9;
const byte PIN_LED = 13;

const unsigned long ANTIRIMBALZO_MS = 30;
const unsigned long TENUTA_SPINTA_MS = 220;
const unsigned long STACCA_DOPO_MS = 600;
const unsigned long PERSONALITA_MS = 20000;   // memoria personalita' (gennaio: 20 s)
const unsigned long FINESTRA_SEGRETO_MS = 3000;
const unsigned long SFARFALLATA_MS = 350;
const byte SFARFALLATE_PER_PARTY = 3;
const byte DURATA_PARTY = 4;                  // attivazioni in Party Mode

Servo arm;
int armAt = ARM_RIPOSO;          // angolo attuale (gradi servo)
bool dopoSpinta = false;         // dopo lo spegnimento i movimenti non si annullano
int pSbirciata = 40, pQuasi = 80;

bool stabileOn = false, ultimoGrezzo = false, prontoPerOn = false;
unsigned long cambiatoAlle = 0, fermoDalle = 0, ultimaAttivazione = 0;
int attivazioni = 0;
bool partyMode = false;
byte partyRestanti = 0;
byte sfarfallate = 0;
unsigned long primaSfarfallata = 0;

// ------------------------------------------------------------ utilita'
bool levettaOn() { return digitalRead(PIN_LEVETTA) == LOW; }

int corsa() { return abs(ARM_SPINTA - ARM_RIPOSO); }

int percento(int angolo) {
  return (long)(angolo - ARM_RIPOSO) * 100 / (ARM_SPINTA - ARM_RIPOSO);
}

int angolo(int pct) {
  return ARM_RIPOSO + (long)(ARM_SPINTA - ARM_RIPOSO) * pct / 100;
}

bool calibrazioneValida() {
  const bool cresc = ARM_RIPOSO < ARM_SBIRCIATA && ARM_SBIRCIATA < ARM_QUASI && ARM_QUASI < ARM_SPINTA;
  const bool decr  = ARM_RIPOSO > ARM_SBIRCIATA && ARM_SBIRCIATA > ARM_QUASI && ARM_QUASI > ARM_SPINTA;
  return (cresc || decr) && corsa() >= 45 && corsa() <= 110 &&
         ARM_RIPOSO >= 5 && ARM_RIPOSO <= 175 && ARM_SPINTA >= 5 && ARM_SPINTA <= 175;
}

void collega() {
  if (!arm.attached()) { arm.write(armAt); arm.attach(PIN_ARM); }
}

// Velocita' 1..8 come a gennaio: stessa DURATA sull'intera corsa.
unsigned int msPerGrado(byte vel) {
  unsigned int durata = vel <= 2 ? 6400 : vel <= 4 ? 1600 : vel <= 6 ? 533 : 160;
  unsigned int ms = durata / corsa();
  return ms < 4 ? 4 : ms;
}

// Pausa che si interrompe se l'utente rimette OFF (prima della spinta).
bool pausa(unsigned long ms) {
  const unsigned long t0 = millis();
  while (millis() - t0 < ms) {
    if (!dopoSpinta && !levettaOn()) return true;
    delay(2);
  }
  return false;
}

// Va alla percentuale pct (limitata ad ARM_QUASI). true = annullato.
bool vai(int pct, byte vel) {
  pct = constrain(pct, 0, pQuasi);
  const int target = angolo(pct);
  const unsigned int ms = msPerGrado(vel);
  collega();
  const int dir = target > armAt ? 1 : -1;
  while (armAt != target) {
    armAt += dir;
    arm.write(armAt);
    delay(ms);
    if (!dopoSpinta && !levettaOn()) return true;
  }
  return false;
}

// Scatto immediato (come myServo.write di gennaio), limitato ad ARM_QUASI.
bool scatta(int pct, unsigned long attesa) {
  pct = constrain(pct, 0, pQuasi);
  collega();
  armAt = angolo(pct);
  arm.write(armAt);
  return pausa(attesa);
}

// Spinta vera: si ferma appena la levetta va su OFF.
void spingi(byte vel) {
  const unsigned int ms = msPerGrado(vel);
  collega();
  const int dir = ARM_SPINTA > armAt ? 1 : -1;
  while (armAt != ARM_SPINTA && levettaOn()) {
    armAt += dir;
    arm.write(armAt);
    delay(ms);
  }
  const unsigned long t0 = millis();
  while (levettaOn() && millis() - t0 < TENUTA_SPINTA_MS) delay(5);
  if (levettaOn()) {
    digitalWrite(PIN_LED, HIGH);
    Serial.println(F("Levetta ancora ON: aumenta ARM_SPINTA di 2 gradi."));
    // si stacca subito dalla levetta: niente stallo nel resto del comportamento
    const int dq = angolo(pQuasi) > armAt ? 1 : -1;
    while (armAt != angolo(pQuasi)) { armAt += dq; arm.write(armAt); delay(4); }
  } else {
    digitalWrite(PIN_LED, LOW);
  }
  dopoSpinta = true;
}

void aRiposo(byte vel) {
  const unsigned int ms = msPerGrado(vel);
  collega();
  const int dir = ARM_RIPOSO > armAt ? 1 : -1;
  while (armAt != ARM_RIPOSO) { armAt += dir; arm.write(armAt); delay(ms); }
  fermoDalle = millis();
}

void lampeggia(byte volte) {
  for (byte i = 0; i < volte; i++) {
    digitalWrite(PIN_LED, HIGH); delay(200);
    digitalWrite(PIN_LED, LOW);  delay(200);
  }
}

// Se una mossa viene annullata (utente su OFF) il comportamento finisce;
// il rientro lo fa sempre esegui().
#define V(p, v)   do { if (vai((p), (v))) return; } while (0)
#define S(p, ms)  do { if (scatta((p), (ms))) return; } while (0)
#define W(ms)     do { if (pausa(ms)) return; } while (0)
#define SPINGI(v) spingi(v)

// Punti della corsa (percentuali). A gennaio: INSIDE=10, OUTSIDE=170.
const int P_BUSSA = 18;   // alza appena lo sportello (bussa da sotto)
#define P_SBIRCIA pSbirciata
#define P_QUASI   pQuasi

// ------------------------------------------------------------ 29 comportamenti
void c01_Normale()        { V(0,5); SPINGI(5); W(300); }
void c02_Lento()          { SPINGI(2); W(300); }
void c03_Veloce()         { SPINGI(8); W(200); }
void c04_VelocitaVariabile() { V(50,3); SPINGI(7); W(300); }
void c05_FintaSingola()   { V(20,5); W(500); SPINGI(5); W(300); }
void c06_DoppiaFinta()    { V(15,5); W(400); V(30,5); W(400); SPINGI(5); W(300); }
void c07_FintaConRitorno(){ V(38,5); W(300); V(25,4); W(200); SPINGI(6); W(300); }
void c08_Cucu()           { V(P_SBIRCIA,4); W(400); V(0,6); W(1000); SPINGI(7); W(300); }
void c09_Tremante() {
  int p = 0;
  while (p < P_QUASI - 5) {
    p += 5;
    S(p, 50); S(p - 2, 50); S(p + 2, 50);
  }
  SPINGI(8); W(300);
}
void c10_PigroEstremo()   { W(random(3000, 5000)); SPINGI(8); W(200); }
void c11_DoppioSpegnimento() {
  SPINGI(6); W(300); V(0,6); W(500);
  V(P_QUASI,7); W(300);             // seconda volta: controlla soltanto
}
void c12_Indeciso()       { V(P_QUASI,5); W(800); V(0,5); W(2000); SPINGI(6); W(300); }
void c13_ToccToc() {
  for (byte i = 0; i < 3; i++) { S(P_BUSSA, 150); S(0, 150); }
  W(500); SPINGI(6); W(300);
}
void c14_Balletto() {
  for (byte i = 0; i < 4; i++) { V(22,6); V(34,6); }
  SPINGI(6); W(300);
}
void c15_Beffa()          { V(P_QUASI,8); W(800); SPINGI(2); W(300); }
void c16_SbattiSportello() {
  SPINGI(6); W(300);
  for (byte i = 0; i < 3; i++) { V(25,8); W(100); V(P_QUASI - 10,8); W(100); }
}
void c17_Sbirciatina()    { V(P_QUASI - 5,1); W(500); SPINGI(8); W(300); }
void c18_ColpiMultipli() {
  SPINGI(6); W(300); V(50,5); W(500);
  V(P_QUASI,6); W(300);             // a gennaio ripremeva: qui solo controllo
}
void c19_Confuso()        { V(P_QUASI,5); W(2000); V(P_QUASI - 15,4); W(800); SPINGI(5); W(300); }
void c20_Sbadiglio()      { V(50,3); W(3000); SPINGI(1); W(300); }
void c21_Impaziente() {
  SPINGI(8); W(150);
  for (byte i = 0; i < 2; i++) { S(P_QUASI - 10, 80); S(P_QUASI, 80); }
}
void c22_Stanco()         { SPINGI(1); W(1000); }
void c23_FalsePartenze() {
  for (byte i = 0; i < 2; i++) { V(31,5); W(300); V(0,5); W(400); }
  SPINGI(6); W(300);
}
void c24_Caos() {
  for (byte i = 0; i < 8; i++) { V(random(0, P_QUASI), random(3, 8)); W(random(100, 500)); }
  SPINGI(6); W(300);
}
void c25_Furtivo()        { SPINGI(1); W(500); }
void c26_Collaudo()       { V(P_QUASI,5); W(1000); V(0,5); W(1500); SPINGI(6); W(300); }
void c27_PartenzaPigra()  { W(5000); SPINGI(8); W(200); }
void c28_Balbettante() {
  int p = 0;
  while (p + 6 < P_QUASI) { p += 6; V(p,5); W(200); }
  SPINGI(5); W(300);
}
void c29_Ciao() {
  SPINGI(6); W(500);
  for (byte i = 0; i < 3; i++) { S(P_QUASI - 10, 200); S(P_QUASI, 200); }
  W(300);
}

void esegui(int quale) {
  Serial.print(F("Comportamento ")); Serial.println(quale);
  dopoSpinta = false;
  switch (quale) {
    case 1: c01_Normale(); break;          case 2: c02_Lento(); break;
    case 3: c03_Veloce(); break;           case 4: c04_VelocitaVariabile(); break;
    case 5: c05_FintaSingola(); break;     case 6: c06_DoppiaFinta(); break;
    case 7: c07_FintaConRitorno(); break;  case 8: c08_Cucu(); break;
    case 9: c09_Tremante(); break;         case 10: c10_PigroEstremo(); break;
    case 11: c11_DoppioSpegnimento(); break; case 12: c12_Indeciso(); break;
    case 13: c13_ToccToc(); break;         case 14: c14_Balletto(); break;
    case 15: c15_Beffa(); break;           case 16: c16_SbattiSportello(); break;
    case 17: c17_Sbirciatina(); break;     case 18: c18_ColpiMultipli(); break;
    case 19: c19_Confuso(); break;         case 20: c20_Sbadiglio(); break;
    case 21: c21_Impaziente(); break;      case 22: c22_Stanco(); break;
    case 23: c23_FalsePartenze(); break;   case 24: c24_Caos(); break;
    case 25: c25_Furtivo(); break;         case 26: c26_Collaudo(); break;
    case 27: c27_PartenzaPigra(); break;   case 28: c28_Balbettante(); break;
    case 29: c29_Ciao(); break;
    default: c01_Normale(); break;
  }
  aRiposo(5);   // qualunque cosa sia successa, rientra e lo sportello ricade
  dopoSpinta = false;
}

// ------------------------------------------------------------ personalita' (come a gennaio)
int scegliComportamento() {
  const int tiro = random(100);
  const int bias = attivazioni >= 10 ? 20 : attivazioni >= 5 ? 10 : 0;
  if (tiro < 60 - bias) return random(1, 5);          // 1-4   normali
  if (tiro < 80 - bias) return random(5, 11);         // 5-10  finte
  if (tiro < 95 + bias / 2) return random(11, 21);    // 11-20 teatrali
  return random(21, 30);                              // 21-29 strani
}

int scegliParty() {
  const int tiro = random(100);
  if (tiro < 50) return random(11, 21);
  if (tiro < 80) return random(21, 30);
  return random(5, 11);
}

void attivaParty() {
  partyMode = true;
  partyRestanti = DURATA_PARTY;
  Serial.println(F("PARTY MODE!"));
  lampeggia(3);
}

// Dopo un ON aspetta SFARFALLATA_MS: se l'utente rimette subito OFF e' una
// "sfarfallata" (conta per il codice segreto) e il braccio non parte.
bool eraUnaSfarfallata() {
  const unsigned long t0 = millis();
  while (millis() - t0 < SFARFALLATA_MS) {
    if (!levettaOn()) {
      const unsigned long ora = millis();
      if (ora - primaSfarfallata > FINESTRA_SEGRETO_MS) { sfarfallate = 1; primaSfarfallata = ora; }
      else sfarfallate++;
      if (sfarfallate >= SFARFALLATE_PER_PARTY) { sfarfallate = 0; attivaParty(); }
      return true;
    }
    delay(5);
  }
  return false;
}

void gestisciAttivazione() {
  if (eraUnaSfarfallata()) return;
  ultimaAttivazione = millis();
  attivazioni++;
  int quale;
  if (COMPORTAMENTO_TEST >= 1 && COMPORTAMENTO_TEST <= 29) {
    quale = COMPORTAMENTO_TEST;
  } else if (partyMode) {
    quale = scegliParty();
    if (--partyRestanti == 0) { partyMode = false; lampeggia(2); }
  } else {
    quale = scegliComportamento();
  }
  esegui(quale);
}

// ------------------------------------------------------------ setup / loop
void setup() {
  pinMode(PIN_LEVETTA, INPUT_PULLUP);
  pinMode(PIN_LED, OUTPUT);
  Serial.begin(115200);
  ultimoGrezzo = levettaOn();
  stabileOn = ultimoGrezzo;
  prontoPerOn = !stabileOn;        // accesa con levetta su ON: aspetta un OFF
  cambiatoAlle = millis();
  if (!ABILITATO || !calibrazioneValida()) {
    Serial.println(F("FERMO: scrivi i 4 angoli, poi ABILITATO = true."));
    digitalWrite(PIN_LED, HIGH);
    return;
  }
  pSbirciata = percento(ARM_SBIRCIATA);
  pQuasi = percento(ARM_QUASI);
  randomSeed(analogRead(A0));
  arm.write(ARM_RIPOSO);
  arm.attach(PIN_ARM);
  delay(400);
  fermoDalle = millis();
  lampeggia(3);                    // come a gennaio: tre lampi = pronta
  Serial.println(F("Servo sul filo verde D10; levetta su D9; RUN tolto col Mac."));
  Serial.println(F("Useless box compatta: 29 comportamenti pronti."));
}

void loop() {
  if (!ABILITATO || !calibrazioneValida()) return;
  const bool g = levettaOn();
  if (g != ultimoGrezzo) { ultimoGrezzo = g; cambiatoAlle = millis(); }
  if (millis() - cambiatoAlle >= ANTIRIMBALZO_MS) stabileOn = g;
  if (!stabileOn) prontoPerOn = true;

  if (stabileOn && prontoPerOn) {
    prontoPerOn = false;
    gestisciAttivazione();
  }
  if (millis() - ultimaAttivazione > PERSONALITA_MS) attivazioni = 0;
  if (arm.attached() && armAt == ARM_RIPOSO && millis() - fermoDalle > STACCA_DOPO_MS) arm.detach();
}

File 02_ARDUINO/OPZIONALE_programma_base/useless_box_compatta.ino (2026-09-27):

// Useless box compatta - un solo MG996R: il braccio apre lo sportello
// spingendolo da sotto e poi abbatte la levetta.
// Cablaggio definitivo: verde D10 = segnale servo; giallo D9 = levetta.
// D9 = levetta (COM a GND, ON a D9), LED "L" su D13.
// Col Mac: RUN tolto e 5 V esterno acceso quando il servo deve muoversi.
// 1) Esegui calibra_braccio.ino e scrivi qui i tre angoli misurati.
// 2) Metti ABILITATO = true e carica. Poi spegni il 5 V esterno, scollega il Mac,
//    inserisci RUN e riaccendi il 5 V esterno.
#include <Servo.h>

const bool ABILITATO = false;
const int ARM_RIPOSO    = 90;   // braccio dentro, sportello chiuso, niente ronzio
const int ARM_SBIRCIATA = 125;  // punta appena fuori (valore di esempio)
const int ARM_SPINTA    = 160;  // levetta scattata + 2..3 gradi (valore di esempio)

const byte PIN_ARM = 10;
const byte PIN_LEVETTA = 9;
const byte PIN_LED = 13;
const unsigned long ANTIRIMBALZO_MS = 30;
const unsigned long TENUTA_SPINTA_MS = 220;   // tempo massimo contro la levetta
const unsigned long STACCA_DOPO_MS = 600;     // poi il servo viene "staccato"

Servo arm;
int armAt = ARM_RIPOSO;
bool ultimoGrezzo = false, stabileOn = false, prontoPerOn = false;
unsigned long cambiatoAlle = 0, fermoDalle = 0;
byte comportamento = 0;

bool calibrazioneValida() {
  const bool crescente   = ARM_RIPOSO < ARM_SBIRCIATA && ARM_SBIRCIATA < ARM_SPINTA;
  const bool decrescente = ARM_RIPOSO > ARM_SBIRCIATA && ARM_SBIRCIATA > ARM_SPINTA;
  const int corsa = abs(ARM_SPINTA - ARM_RIPOSO);
  return (crescente || decrescente) && corsa >= 45 && corsa <= 110 &&
         ARM_RIPOSO >= 5 && ARM_RIPOSO <= 175 && ARM_SPINTA >= 5 && ARM_SPINTA <= 175;
}

bool levettaOn() { return digitalRead(PIN_LEVETTA) == LOW; }

void aggiornaLevetta() {
  const bool g = levettaOn();
  if (g != ultimoGrezzo) { ultimoGrezzo = g; cambiatoAlle = millis(); }
  if (millis() - cambiatoAlle >= ANTIRIMBALZO_MS) stabileOn = g;
  if (!stabileOn) prontoPerOn = true;
}

void collega() {
  if (!arm.attached()) { arm.write(armAt); arm.attach(PIN_ARM); }
}

// Muove a passi di 1 grado. msGrado piccolo = veloce.
// Se durante l'andata l'utente rimette OFF, si ferma (ritorna true).
bool muovi(int target, unsigned int msGrado, bool fermatiSeOff) {
  collega();
  const int dir = target > armAt ? 1 : -1;
  while (armAt != target) {
    armAt += dir;
    arm.write(armAt);
    delay(msGrado);
    if (fermatiSeOff && !levettaOn()) return true;
  }
  return false;
}

// Frazione della corsa fra riposo e spinta (0..100 %)
int angoloA(int percento) {
  return ARM_RIPOSO + (long)(ARM_SPINTA - ARM_RIPOSO) * percento / 100;
}

void aRiposo(unsigned int msGrado) {
  muovi(ARM_RIPOSO, msGrado, false);
  fermoDalle = millis();
}

void spingi(unsigned int msGrado) {
  if (muovi(ARM_SPINTA, msGrado, true)) { aRiposo(6); return; }
  const unsigned long t0 = millis();
  while (levettaOn() && millis() - t0 < TENUTA_SPINTA_MS) delay(5);
  if (levettaOn()) {
    // non ha abbattuto la levetta: non insiste, segnala e torna dentro
    digitalWrite(PIN_LED, HIGH);
    Serial.println(F("Levetta ancora ON: aumenta ARM_SPINTA di 2 gradi."));
  } else {
    digitalWrite(PIN_LED, LOW);
  }
  aRiposo(5);
}

void comporta(byte quale) {
  Serial.print(F("Comportamento ")); Serial.println(quale + 1);
  switch (quale) {
    case 0:                                   // deciso
      spingi(4);
      break;
    case 1:                                   // pigro: aspetta, poi lento
      delay(1500);
      if (!levettaOn()) return;
      spingi(12);
      break;
    case 2:                                   // sbircia, rientra, poi colpisce
      if (muovi(ARM_SBIRCIATA, 8, true)) { aRiposo(6); return; }
      delay(900);
      muovi(angoloA(10), 8, false);
      delay(700);
      if (!levettaOn()) { aRiposo(6); return; }
      spingi(3);
      break;
    case 3:                                   // esitante: si avvicina e trema
      if (muovi(angoloA(80), 7, true)) { aRiposo(6); return; }
      for (byte i = 0; i < 3; i++) {
        muovi(angoloA(70), 6, false);
        muovi(angoloA(80), 6, false);
      }
      delay(300);
      spingi(8);
      break;
    default:                                  // doppio colpo di sportello
      muovi(angoloA(45), 4, false); muovi(angoloA(15), 4, false);
      muovi(angoloA(45), 4, false); muovi(angoloA(15), 4, false);
      delay(400);
      if (!levettaOn()) { aRiposo(6); return; }
      spingi(4);
      break;
  }
}

void setup() {
  pinMode(PIN_LEVETTA, INPUT_PULLUP);
  pinMode(PIN_LED, OUTPUT);
  Serial.begin(115200);
  ultimoGrezzo = levettaOn(); stabileOn = ultimoGrezzo;
  prontoPerOn = !stabileOn;   // acceso con levetta su ON: aspetta un OFF
  cambiatoAlle = millis();
  if (!ABILITATO || !calibrazioneValida()) {
    Serial.println(F("FERMO: scrivi i 3 angoli, poi ABILITATO = true."));
    digitalWrite(PIN_LED, HIGH);
    return;
  }
  randomSeed(analogRead(A0));
  arm.write(ARM_RIPOSO);
  arm.attach(PIN_ARM);
  delay(400);
  fermoDalle = millis();
  Serial.println(F("Useless box compatta pronta."));
}

void loop() {
  if (!ABILITATO || !calibrazioneValida()) return;
  aggiornaLevetta();
  if (stabileOn && prontoPerOn) {
    prontoPerOn = false;
    comporta(comportamento);
    comportamento = (comportamento + 1 + random(0, 2)) % 5;
  }
  // a riposo il servo viene staccato: niente ronzio e meno corrente
  if (arm.attached() && armAt == ARM_RIPOSO && millis() - fermoDalle > STACCA_DOPO_MS) arm.detach();
}
